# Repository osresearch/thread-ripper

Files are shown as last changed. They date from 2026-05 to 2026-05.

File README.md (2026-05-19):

# Thread cutting attachment for Emco Unimat SL microlathe
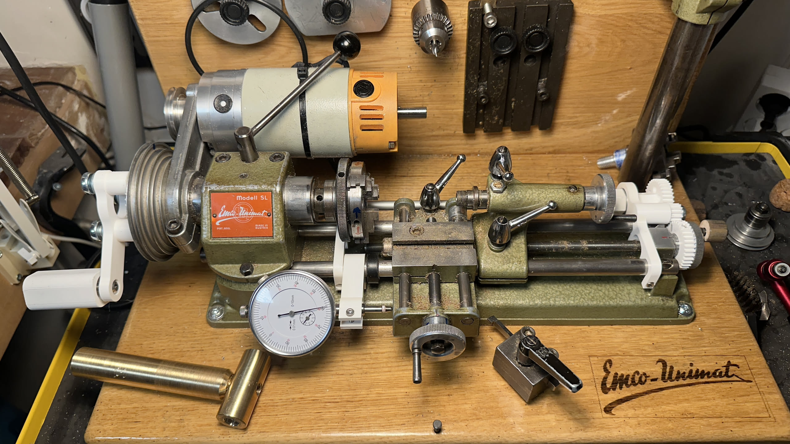
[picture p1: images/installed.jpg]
Image of the lathe with thread cutting attachment installed


**WARNING** Never power up the lathe with a threading gear on the cross shaft.
The 3D printed pieces are designed for hand-operation only.
Remove the gear from the cross shaft before engaging the motor.

## Setup

* Paint the section to be threaded.
* Set an end stop for the carriage.
* Move the carriage to the right side of the threaded section.
* Feed the tool in until it just makes contact.
* **Remove motor belt** -- for safety and also it makes it easier to turn the spindle.
* Install the correct change gears for the desired thread pitch.
* Install the crank handle if desired.
* Turn the spindle and feedwheel to do a scratch test.
* At the end of the threaded section, back out the tool a whole turn.
* Turn the spindle and feedwheel backwards to return the carriage to the start of the threaded section.
* Feed in the tool 0.1 or 0.2mm further and repeat.  It's not very rigid, so shallow cuts are better.

## Pitches

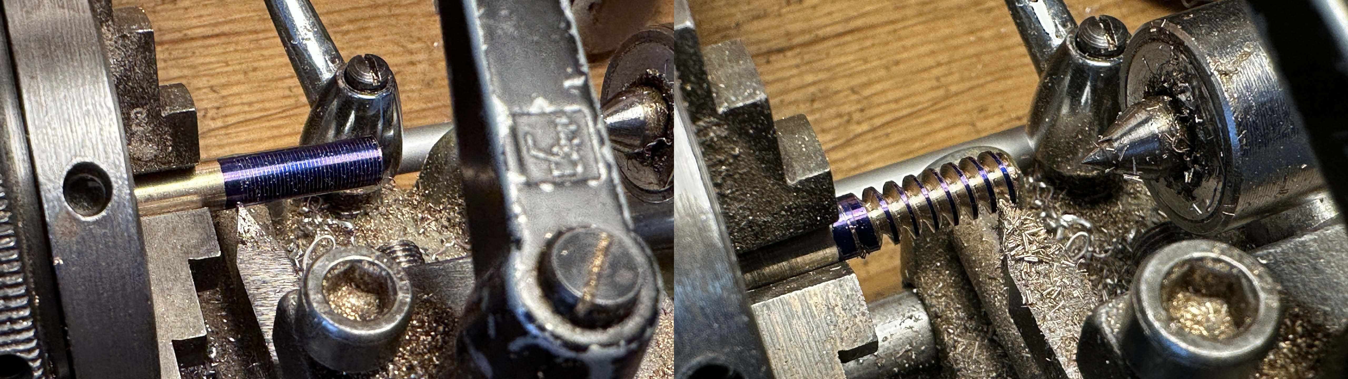
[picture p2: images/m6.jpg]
Two threads cut, one very fine and one very coarse


Thread pitch is controlled by installing a gear T1 on the crossshaft and T2 on the spindle.
The 0.5 fine pitch on the left is with the 30 on the cross shaft and the 60 on the spindle,
while the 2.0 coarse pitch on the right is with the 60 on the cross shaft and 30 on the spindle.

All of the combinations sum to 90 teeth and the spacing between cross shaft and spindle is 54mm.
This is means a 1.2 modulus for the gears (45 tooth * 1.2 module == 54mm diameter).

Pitch | T1 | T2 | Err % | Usage
------|----|----|-------|------
 0.25 | 18 | 72 | +0.00 | M2 fine
 0.35 | 23 | 67 | +0.67 | M3 fine
 0.40 | 26 | 64 | -0.62 | M2
 0.50 | 30 | 60 | +0.00 | M3, M4 fine, M5 fine
 0.70 | 37 | 53 | +0.19 | M4
 0.75 | 39 | 51 | -1.47 | M6 fine
 0.80 | 40 | 50 | +0.00 | M5
 1.00 | 45 | 45 | +0.00 | M6, M8 fine, M12 spindle
 1.25 | 50 | 40 | +0.00 | M8, M10 fine
 1.50 | 54 | 36 | +0.00 | M10, M12 fine, M14 fine
 1.75 | 57 | 33 | +2.27 | M12 
 2.00 | 60 | 30 | +0.00 | M14

60 teeth is the largest that fits on the cross shaft, but you probably aren't turning bigger than M14 on
this itty bitty lathe anyway.

## Parts

The cross shaft is 8mm aluminum from the hardware store.

The bearings are 8mm ID, 22mm OD skate bearings and press fit into the printed mounting bracket.

The reversing gear doesn't have a bearing due to clearance issues, although it probably should.

The set screw for the feedwheel handle is M2.5.

All other hardware is M3.

* `ThreadCutter-WayMount.stl` -- press fit 22x8mm bearing, secure with M3x25 to front way
* `ThreadCutter-WayMountFeed.stl` -- press fit 22x8mm bearing, secure with M3x25 to front way
* `ThreadCutter-FeedGearCrossshaft.stl` -- self-tap an M3 set screw
* `ThreadCutter-FeedGearHandwheel.stl` -- self-tap an M2.5 screw, be sure it does not protrude into the gear teeth
* `ThreadCutter-FeedReverser.stl` -- M6 screw into the `WayMountFeed`
* `ThreadCutter-SpindleNut.stl` -- self-tap an M3 set screw
* `ThreadCutter-ChangeGear30.stl`
* `ThreadCutter-ChangeGear45.stl` -- print twice
* `ThreadCutter-ChangeGear60.stl`
* `ThreadCutter-EndStop.stl` -- optional for holding a dial indicator

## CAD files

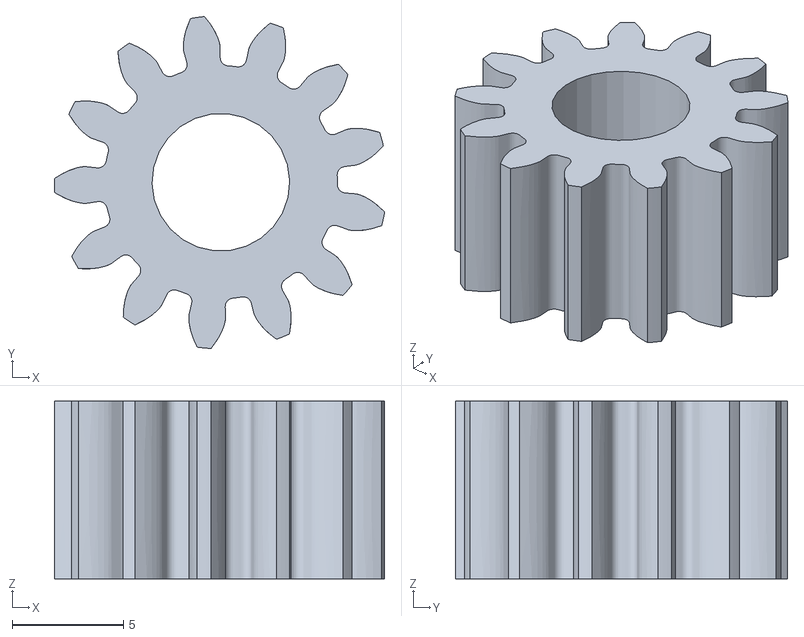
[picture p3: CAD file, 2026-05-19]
stl/ThreadCutter-FeedReverser.stl
14.9 x 15.0 x 8.00

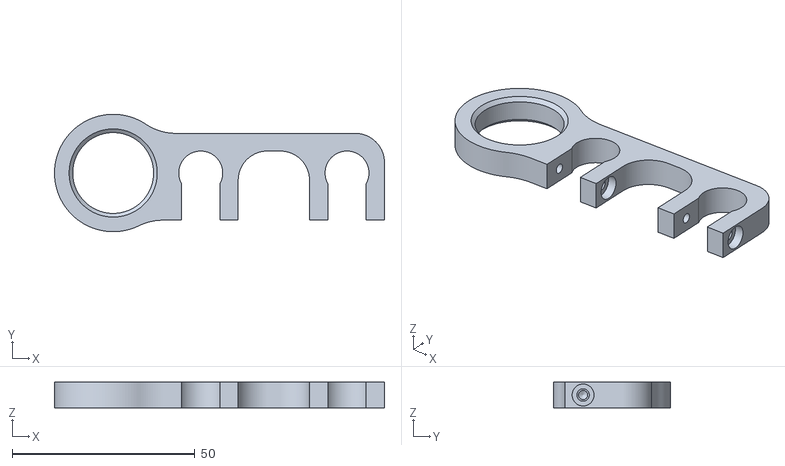
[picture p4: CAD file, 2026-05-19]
stl/ThreadCutter-WayMount.stl
90.2 x 32.1 x 7.00

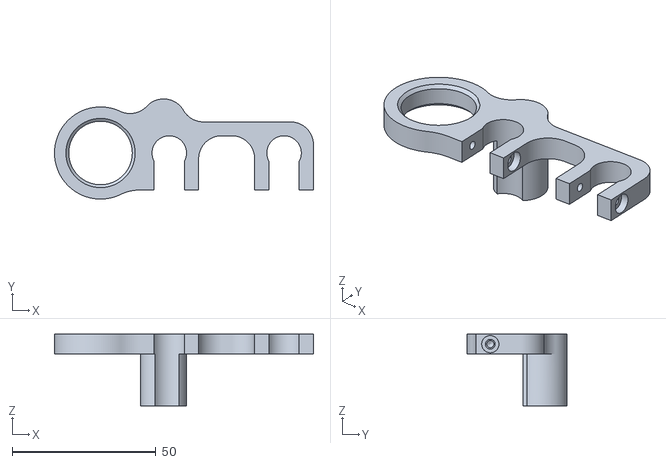
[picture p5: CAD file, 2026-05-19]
stl/ThreadCutter-WayMountFeed.stl
90.2 x 34.9 x 25.0

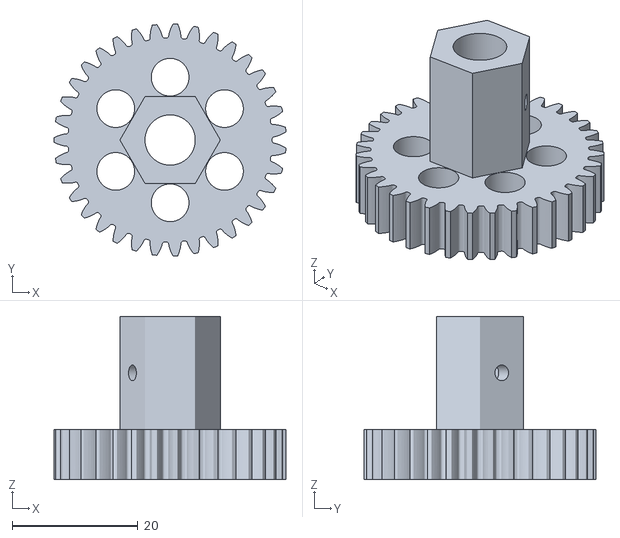
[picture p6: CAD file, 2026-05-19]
stl/ThreadCutter-FeedGearCrossshaft.stl
37.0 x 37.0 x 26.0

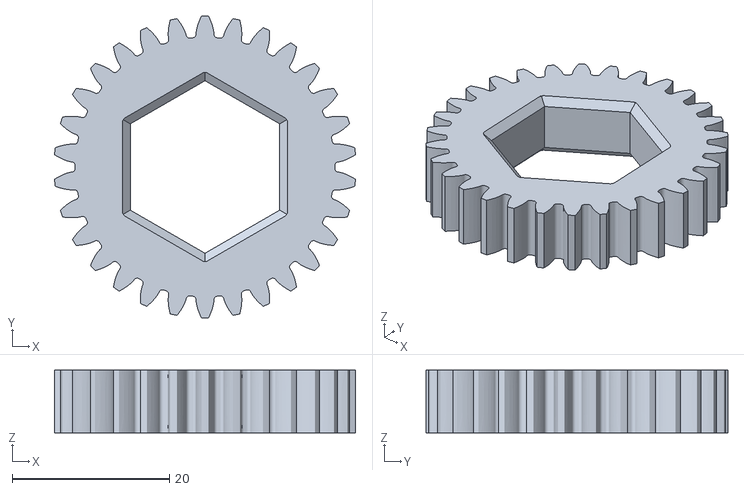
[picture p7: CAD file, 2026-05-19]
stl/ThreadCutter-ChangeGear30.stl
38.3 x 38.4 x 8.00

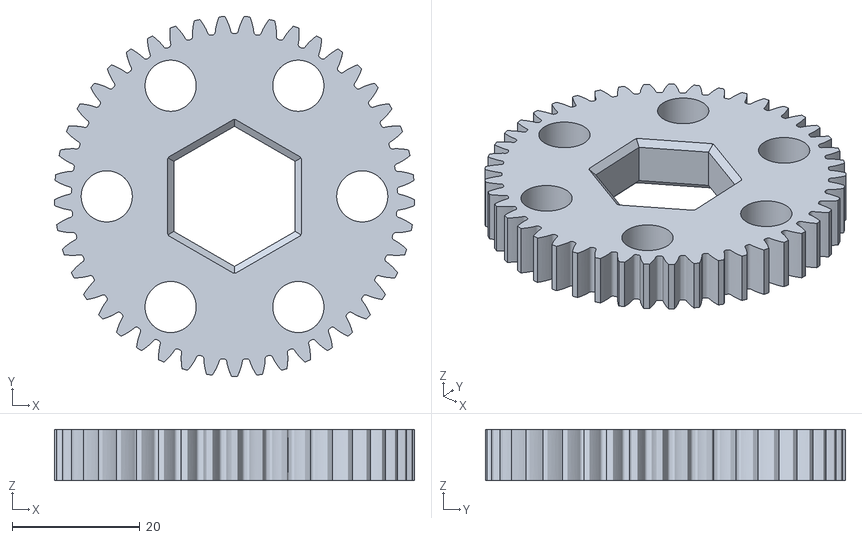
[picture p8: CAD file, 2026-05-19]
stl/ThreadCutter-ChangeGear45.stl
56.4 x 56.4 x 8.00

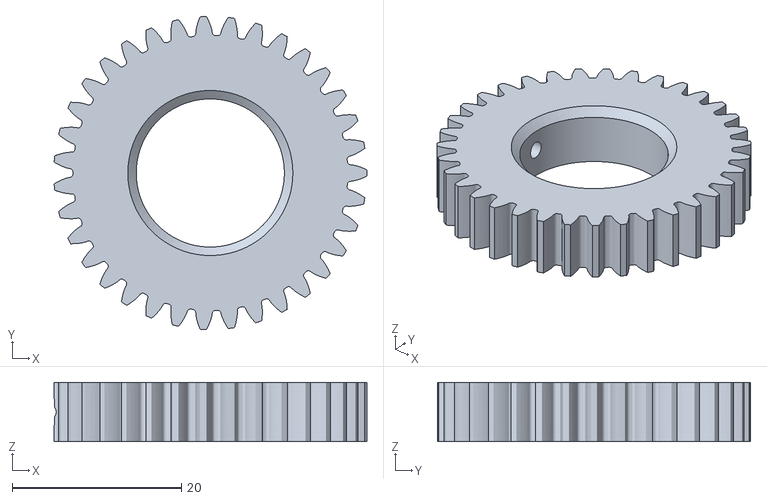
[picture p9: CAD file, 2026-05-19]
stl/ThreadCutter-FeedGearHandwheel.stl
37.0 x 37.0 x 7.00

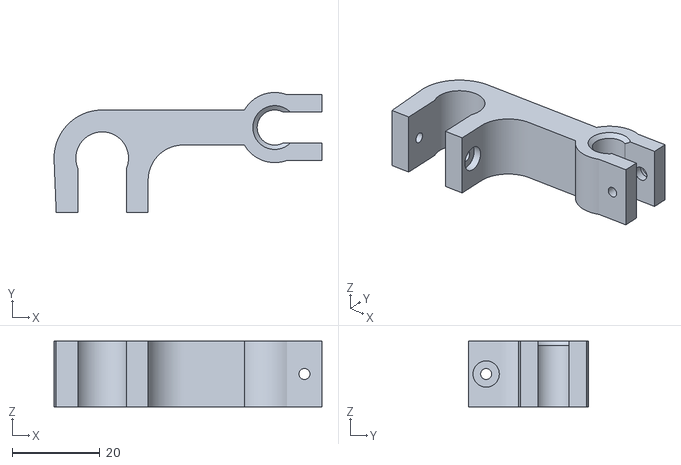
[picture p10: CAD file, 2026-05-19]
stl/ThreadCutter-EndStop.stl
61.2 x 27.4 x 15.0

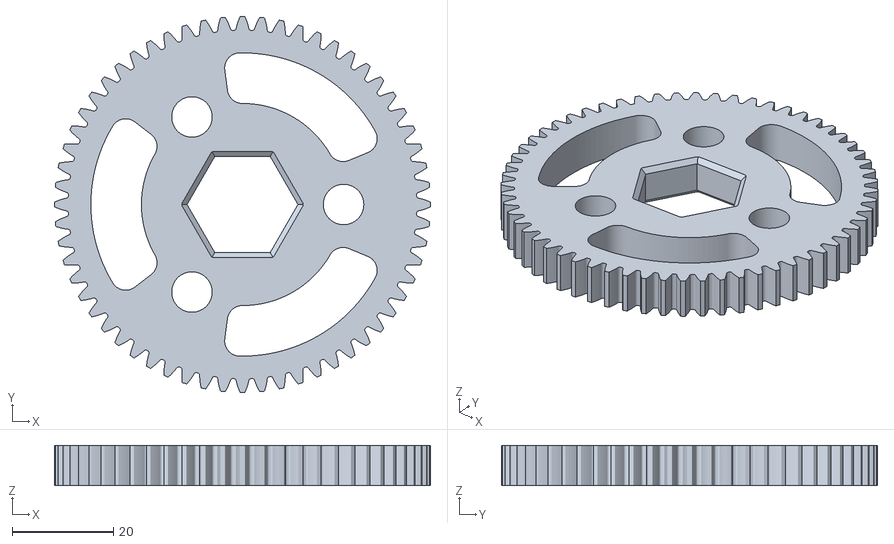
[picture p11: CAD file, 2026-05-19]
stl/ThreadCutter-ChangeGear60.stl
74.4 x 74.4 x 8.00

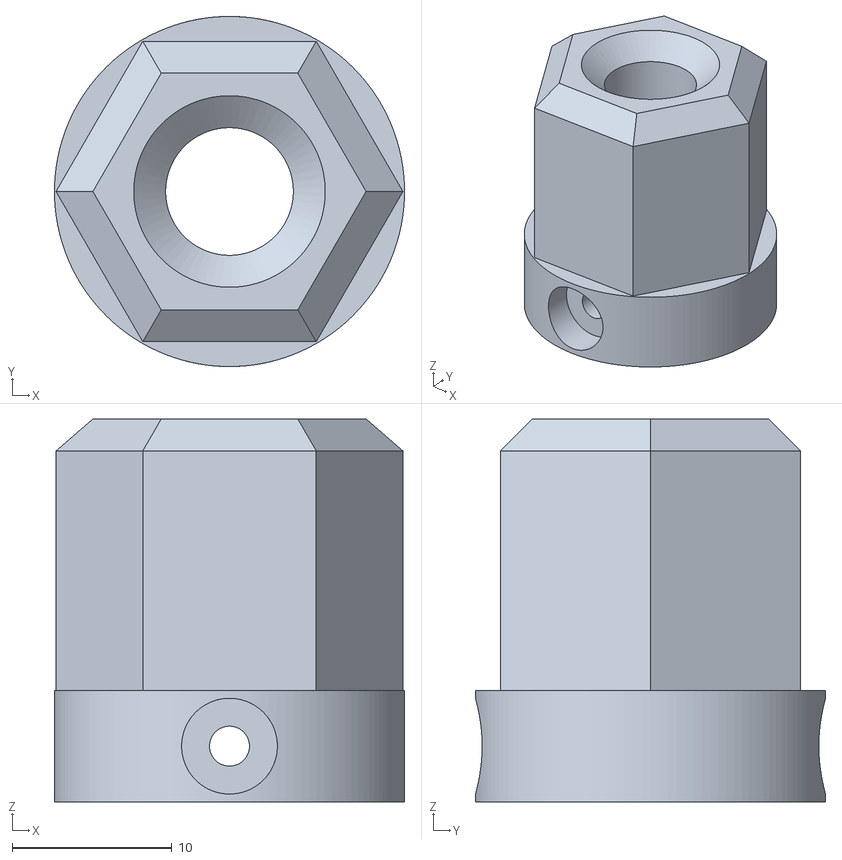
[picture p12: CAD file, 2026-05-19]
stl/ThreadCutter-SpindleNut.stl
21.9 x 21.9 x 24.0
